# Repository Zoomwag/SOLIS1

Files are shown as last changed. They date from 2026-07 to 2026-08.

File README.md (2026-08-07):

<div align="center">

# Solis 1 CanSat


</div>

---

## About

**Solis 1** is my custom-built CanSat project, designed to fit all the main systems of a small satellite inside a compact cylindrical enclosure.

The CanSat measures approximately:

* **64 mm in diameter**
* **110 mm tall**

The project includes a custom flight computer PCB, a lightweight enclosure, onboard software, a recovery system and a ground station.

The aim of Solis 1 is to create a compact and system that can collect data during a test flight, transmit information back to the ground and safely return for recovery.

---

## Project Goals

The main goals of the project are to:

* Design a fully custom flight computer
* Fit the complete system inside the CanSat enclosure
* Collect and store flight data
* Transmit data to a ground station
* Create a lightweight but strong structure
* Test the CanSat through multiple ground and flight tests
* Learn more about PCB design, electronics, programming and engineering

---

## CanSat Design

The outside structure is designed to protect the electronics while keeping the CanSat lightweight and easy to assemble.

The design includes mounting points for the flight computer, battery and other internal parts. It will also allow the CanSat to be opened for maintenance, testing and repairs.

<!-- Add an image or render of the complete CanSat here -->

---

## Flight Computer PCB

The Solis 1 flight computer is a custom PCB designed specifically for this project.

It will connect the main electronics together and reduce the amount of loose wiring inside the CanSat. The PCB is being designed to be compact, organised and easy to test.

<!-- Add a PCB render or photograph here -->

---

## PCB Schematic

The schematic shows how the components  on the flight computer are connected together



---

## PCB Layout

The board is designed to fit inside the Solis 1 enclosure while leaving enough space for mounting holes, connectors and other internal parts.







I even included some really nice graphics on the back

---

## BOM


Here you can see the bom for Solis 1

---

## Mechanical Design

This includes the outer enclosure, internal mounts, PCB supports and recovery-system parts. The design needs to be compact, lightweight and strong enough to protect the electronics during testing and landing.






---

---

## Future Plans

Once the first version of Solis 1 has been assembled, it will go through several stages of testing.

These will include checking the electronics, testing the software, confirming that the ground station receives data and making sure the enclosure protects the internal components.

The results from each test will be used to improve future versions of the CanSat.

---

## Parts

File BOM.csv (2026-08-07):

Name | Purpose | Qty | Total (USD) | Link | Distributor
PCB | PCB | 5 | $130.00 | JLCPCB | jlcpcb
Adafruit RFM95W LoRa Radio Transceiver Breakout - 868 or 915 MHz (RadioFruit) | LORA | 1 | $27.00 | https://thepihut.com/products/adafruit-rfm95w-lora-radio-transceiver-breakout-868-or-915-mhz | thepihut
Adafruit BME280 I2C or SPI Temperature Humidity Pressure Sensor (STEMMA QT) | environmetnal sensor | 1 | $20.00 | https://thepihut.com/products/adafruit-bme280-i2c-or-spi-temperature-humidity-pressure-sensor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 | thepihut
MicroSD card breakout board+ | SDcard | 1 | $11.00 | https://thepihut.com/products/adafruit-microsd-card-breakout-board?variant=27739995217 | thepihut
Adafruit LSM6DSOX + LIS3MDL - Precision 9 DoF IMU (STEMMA QT / Qwiic | IMU | 5 | $27.00 | https://thepihut.com/products/adafruit-lsm6dsox-lis3mdl-precision-9-dof-imu?variant=31618642182206 | thepihut
2.0mm Pitch 6-pin Cable Matching Pair - JST PH Compatible | wire | 2 | $3.00 | https://thepihut.com/products/2-0mm-pitch-6-pin-cable-matching-pair-jst-ph-compatible?variant=40200490877123 | thepihut
Qwiic/STEMMA QT-Compatible Cable - JST-SH 4-Pin (50mm) | wire | 6 | $10.00 | https://thepihut.com/products/stemma-qt-qwiic-jst-sh-4-pin-cable?variant=31257729073214 | thepihut
Shipping |  |  | $5.50
Total |  |  | $233.50

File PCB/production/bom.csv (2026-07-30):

Designator | Footprint | Quantity | Value | LCSC Part #
C15, C18, C22 | 0805 | 3 | 10uF
C16, C19 | 0805 | 2 | 2.2uF
C17 | 1206 | 1 | 47uF
C20 | 1206 | 1 | 22uF
C21, C24 | 0805 | 2 | 1uF
C23 | 0603 | 1 | 100nF
D1 | 0805 | 1 | LED
D3 | D_SMA | 1 | SS14-E3/5AT
F2 | MFNSMF0758X2 | 1 | MF-NSMF075_8X-2
IC4 | SON40P220X200X80-11N | 1 | BQ25185DLHR
IC5 | ESP32S3WROOM1UN16R8 | 1 | ESP32-S3-WROOM-1U-N16R8
J11, J15, J16, J4, J5 | JST_SH_BM04B-SRSS-TB_1x04-1MP_P1.00mm_Vertical | 5 | Conn_01x04_Socket
J12, J13 | JST_PH_B8B-PH-K_1x08_P2.00mm_Vertical | 2 | Conn_01x08_Socket
J14 | PinHeader_1x09_P2.54mm_Vertical | 1 | Conn_01x09_Socket
J6 | USB_C_Receptacle_GCT_USB4105-xx-A_16P_TopMnt_Horizontal | 1 | USB_C_Receptacle_USB2.0_16P
J7 | PinHeader_1x02_P2.54mm_Vertical | 1 | Battery
L2 | DFE2HCAH1R0MJ0L | 1 | 1uH
R10, R17, R23, R28 | 0603 | 4 | 10K
R11 | 0603 | 1 | 0
R15, R16 | 0603 | 2 | 5.1K
R18 | 0603 | 1 | 18K
R19 | 0603 | 1 | 1K
R20 | 0603 | 1 | 511K
R21 | 0603 | 1 | 91K
R22 | 0603 | 1 | 100K
R24, R25 | 0603 | 2 | 22
R26, R27 | 0603 | 2 | 4.7K
S2 | SSAJ110100_1 | 1 | SSAJ110100
SW5, SW6 | SW_Push_SPST_NO_Alps_SKRK | 2 | SW_Push
U3 | SOTFL50P160X60-8N | 1 | TPS631000DRLR

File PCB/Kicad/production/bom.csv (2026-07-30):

Designator | Footprint | Quantity | Value | LCSC Part #
AC2 | LSM6DS3USTR | 1 | LSM6DSOTR
C1, C15, C18, C22, C5 | 0805 | 5 | 10uF
C16, C19 | 0805 | 2 | 2.2uF
C17, C6 | 1206 | 2 | 47uF
C2, C23, C25, C26, C27, C28, C4, C8 | 0603 | 8 | 100nF
C20 | 1206 | 1 | 22uF
C21, C24, C3 | 0805 | 3 | 1uF
C7 | 1206 | 1 | 470uF
D1, D2 | 0805 | 2 | LED
D3, D4 | D_SMA | 2 | SS14-E3/5AT
F2 | MFNSMF0758X2 | 1 | MF-NSMF075_8X-2
IC1 | SOT65P210X110-6N | 1 | TPS22919DCKT
IC4 | SON40P220X200X80-11N | 1 | BQ25185DLHR
IC5 | ESP32S3WROOM1UN16R8 | 1 | ESP32-S3-WROOM-1U-N16R8
IC6 | BMP390 | 1 | BMP390
J1 | 1040310811 | 1 | Micro_SD_Card_Det1
J10 | PinHeader_2x09_P2.54mm_Vertical | 1 | Camera
J2 | PinHeader_1x09_P2.54mm_Vertical | 1 | LORA MODULE
J3 | PinHeader_1x03_P2.54mm_Vertical | 1 | Conn_01x03_Pin
J6 | USB_C_Receptacle_GCT_USB4105-xx-A_16P_TopMnt_Horizontal | 1 | USB_C_Receptacle_USB2.0_16P
J7 | PinHeader_1x02_P2.54mm_Vertical | 1 | Battery
J9 | PinHeader_1x04_P2.54mm_Vertical | 1 | Conn_01x04_Socket
L2 | DFE2HCAH1R0MJ0L | 1 | 1uH
R1, R24, R25 | 0603 | 3 | 22
R10, R17, R23, R28, R3, R4, R5, R6, R7, R8, R9 | 0603 | 11 | 10K
R11 | 0603 | 1 | 0
R12, R26, R27 | 0603 | 3 | 4.7K
R13, R2, R22 | 0603 | 3 | 100K
R14 | 0603 | 1 | 220
R15, R16 | 0603 | 2 | 5.1K
R18 | 0603 | 1 | 18K
R19 | 0603 | 1 | 1K
R20 | 0603 | 1 | 511K
R21 | 0603 | 1 | 91K
SW5, SW6 | SW_Push_SPST_NO_Alps_SKRK | 2 | SW_Push
TP1 | TestPoint_Pad_1.0x1.0mm | 1 | GND1
TP2 | TestPoint_Pad_1.0x1.0mm | 1 | TestPoint
TP3 | TestPoint_Pad_1.0x1.0mm | 1 | GND2
TP4 | TestPoint_Pad_1.0x1.0mm | 1 | VBAT
TP5 | TestPoint_Pad_1.0x1.0mm | 1 | SYS_SW
TP6 | TestPoint_Pad_1.0x1.0mm | 1 | 3v3
TP8 | TestPoint_Pad_1.0x1.0mm | 1 | SDA
TP9 | TestPoint_Pad_1.0x1.0mm | 1 | SCL
U3 | SOTFL50P160X60-8N | 1 | TPS631000DRLR

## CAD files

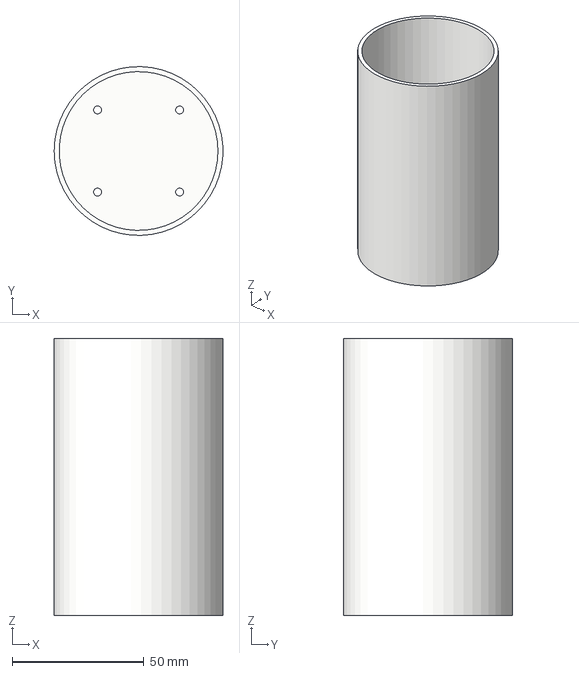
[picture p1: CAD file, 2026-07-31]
SOLIS CAD/3D Print Files/Shell.step
63.9 x 64.0 x 105.0 mm

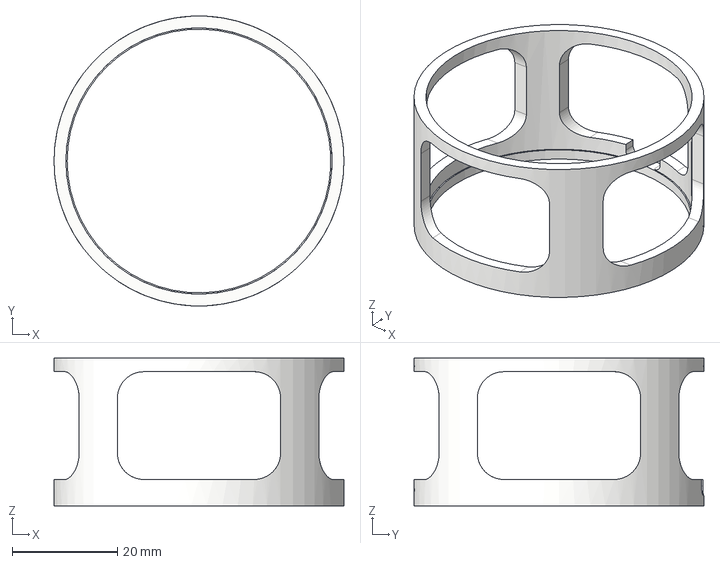
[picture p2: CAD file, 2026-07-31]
SOLIS CAD/3D Print Files/Flight computer mount.step
55.0 x 55.0 x 28.0 mm

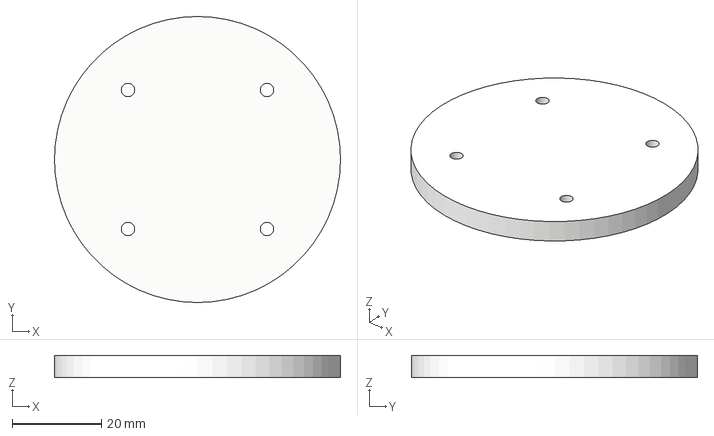
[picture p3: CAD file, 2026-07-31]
SOLIS CAD/3D Print Files/LID.step
64.0 x 64.0 x 5.00 mm

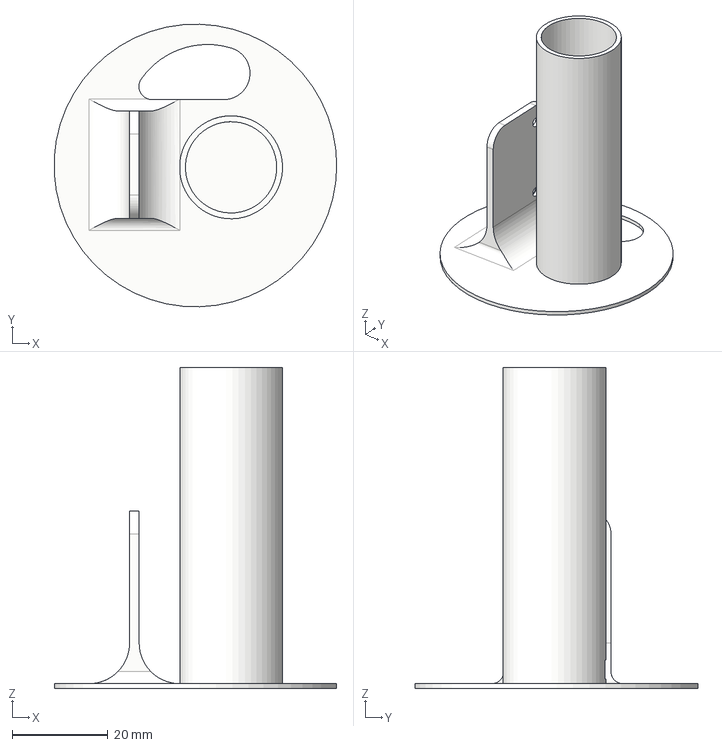
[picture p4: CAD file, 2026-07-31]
SOLIS CAD/3D Print Files/Sensor and battery bay.step
58.9 x 59.0 x 67.0 mm

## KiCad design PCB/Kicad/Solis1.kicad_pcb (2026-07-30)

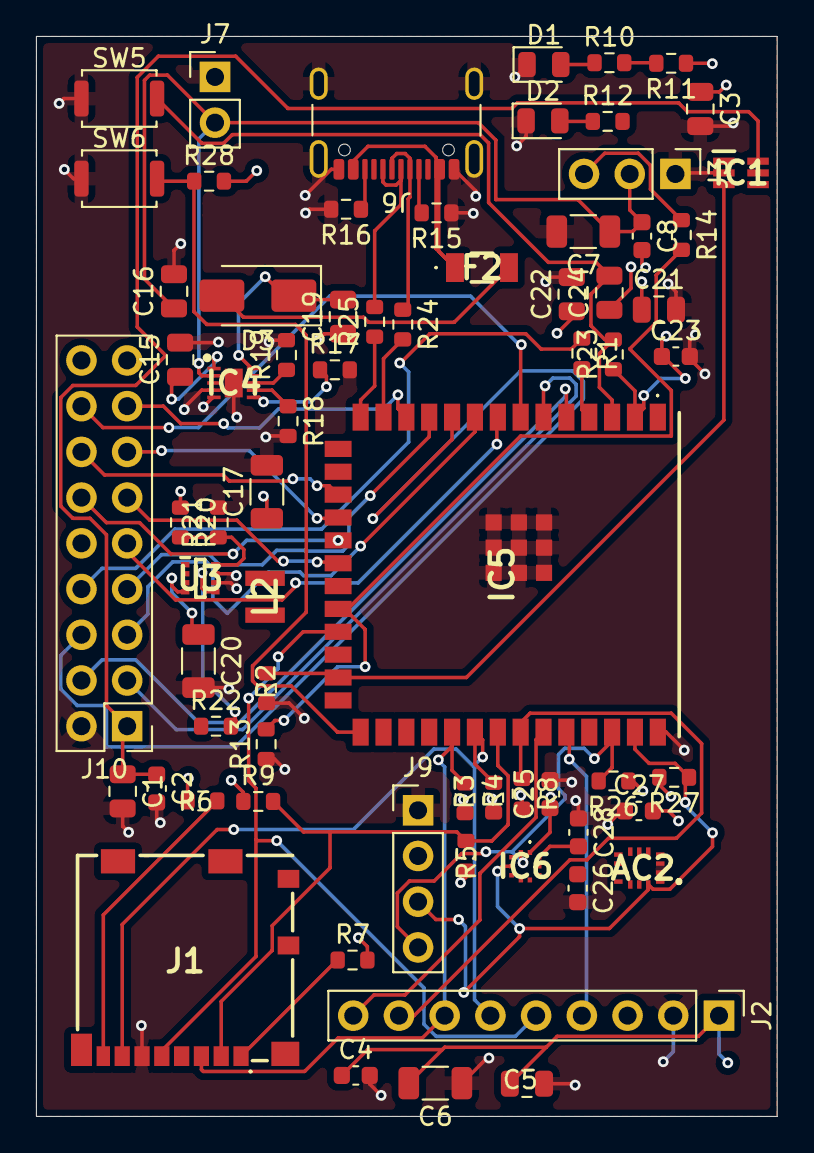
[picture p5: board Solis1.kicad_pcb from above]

Board: 4 copper layers, 41.2 x 60.0 mm, 69 parts (0 on the bottom side), 55 nets.

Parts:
AC2: LSM6DSOTR; LSM6DS3USTR
C1, C5, C15, C22: 10uF; C_0805_2012Metric
C2, C4, C8, C23, C25, C26, C27, C28: 100nF; C_0603_1608Metric
C3, C21, C24: 1uF; C_0805_2012Metric
C6, C17: 47uF; C_1206_3216Metric
C7: 470uF; C_1206_3216Metric
C16, C19: 2.2uF; C_0805_2012Metric
C20: 22uF; C_1206_3216Metric
D1, D2: LED; LED_0805_2012Metric
D3: SS14-E3/5AT; D_SMA
F2: MF-NSMF075_8X-2; MFNSMF0758X2
IC1: TPS22919DCKT; SOT65P210X110-6N
IC4: BQ25185DLHR; SON40P220X200X80-11N
IC5: ESP32-S3-WROOM-1U-N16R8; ESP32S3WROOM1UN16R8
IC6: BMP390
J1: Micro_SD_Card_Det1; 1040310811
J2: LORA MODULE; PinHeader_1x09_P2.54mm_Vertical
J3: Conn_01x03_Pin; PinHeader_1x03_P2.54mm_Vertical
J6: USB_C_Receptacle_USB2.0_16P; USB_C_Receptacle_GCT_USB4105-xx-A_16P_TopMnt_Horizontal
J7: Battery; PinHeader_1x02_P2.54mm_Vertical
J9: Conn_01x04_Socket; PinHeader_1x04_P2.54mm_Vertical
J10: Camera; PinHeader_2x09_P2.54mm_Vertical
L2: 1uH; DFE2HCAH1R0MJ0L
R1, R24, R25: 22; R_0603_1608Metric
R2, R13, R22: 100K; R_0603_1608Metric
R3, R4, R5, R6, R7, R8, R9, R10, R17, R23, R28: 10K; R_0603_1608Metric
R11: 0; R_0603_1608Metric
R12, R26, R27: 4.7K; R_0603_1608Metric
R14: 220; R_0603_1608Metric
R15, R16: 5.1K; R_0603_1608Metric
R18: 18K; R_0603_1608Metric
R19: 1K; R_0603_1608Metric
R20: 511K; R_0603_1608Metric
R21: 91K; R_0603_1608Metric
SW5, SW6: SW_Push; SW_Push_SPST_NO_Alps_SKRK
U3: TPS631000DRLR; SOTFL50P160X60-8N

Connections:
+3V3: AC2.5 (VDDIO), AC2.8 (VDD), AC2.12 (CS), C3.1, C4.1, C5.1, C6.2, C17.1, C21.1, C22.1, C23.1, C25.1, C26.1, C27.2, C28.2, IC1.1 (IN), IC5.2 (3V3), IC6.1 (VDDIO), IC6.6 (CSB), IC6.10 (VDD), J1.4 (VDD), J2.1, J9.2, R3.2, R4.2, R5.1, R6.1, R7.2, R8.2, R9.1, R11.1, R20.1, R23.1, R26.1, R27.2, R28.2, U3.1 (VOUT)
/CAM_3V3: C1.1, C2.1, IC1.5 (QOD), IC1.6 (OUT), J10.1, R12.2
/CAM_PWR: IC1.3 (ON), IC5.25 (IO48), R2.1
/CHARGER_IN: C19.2, D3.1 (K), IC4.10 (IN)
/Camera_D0: IC5.7 (IO7), J10.16
/Camera_D1: IC5.12 (IO8), J10.15
/Camera_D2: IC5.17 (IO9), J10.14
/Camera_D3: IC5.18 (IO10), J10.13
/Camera_D4: IC5.19 (IO11), J10.12
/Camera_D5: IC5.20 (IO12), J10.11
/Camera_D6: IC5.21 (IO13), J10.10
/Camera_D7: IC5.8 (IO15), J10.9
/Camera_HREF: IC5.10 (IO17), J10.6
/Camera_PCLK: IC5.11 (IO18), J10.7
/Camera_SCCB_SCL: IC5.6 (IO6), J10.3
/Camera_SCCB_SDA: IC5.5 (IO5), J10.4
/Camera_VSYNC: IC5.9 (IO16), J10.5
/Camera_XCLK: IC5.4 (IO4), R1.2
/LORA_CS: IC5.34 (IO41), J2.8, R8.1
/LORA_DIO0: IC5.36 (RXD0), J2.4
/LORA_RST: IC5.35 (IO42), J2.9
/SD_CS: IC5.33 (IO40), J1.2 (DAT3/CD), R5.2, R9.2
/SPI_MISO: IC5.32 (IO39), J1.7 (DAT0), J2.6, R4.1
/SPI_MOSI: IC5.31 (IO38), J1.3 (CMD), J2.7, R3.1
/SPI_SCK: IC5.23 (IO21), J1.5 (CLK), J2.5
/SYS_RAW: C15.1, C20.1, IC4.1 (SYS), R22.1, U3.4 (VIN)
/Sensor_I²C_SCL: AC2.13 (SCL), IC5.38 (IO2), IC6.2 (SCK), J9.4, R26.2
/Sensor_I²C_SDA: AC2.14 (SDA), IC5.39 (IO1), IC6.4 (SDI), J9.3, R27.1
/Servo1_PWM: IC5.22 (IO14), R13.2, R14.2
/USB_D+: J6.A6 (D+), J6.B6 (D+), R25.2
/USB_D-: J6.A7 (D-), J6.B7 (D-), R24.1
/USB_FUSED: D3.2 (A), F2.2
/USB_VBUS: F2.1, J6.A4 (VBUS), J6.A9 (VBUS), J6.B4 (VBUS), J6.B9 (VBUS)
/VBAT: C7.1, C8.1, C16.1, IC4.2 (BAT), J3.2, J7.2
GND: AC2.1 (SDO/SA0), AC2.2 (SDX), AC2.3 (SCX), AC2.6 (GND_1), AC2.7 (GND_2), C1.2, C2.2, C3.2, C4.2, C5.2, C6.1, C7.2, C8.2, C15.2, C16.2, C17.2, C19.1, C20.2, C21.2, C22.2, C23.2, C24.1, C25.2, C26.2, C27.1, C28.1, D1.1 (K), D2.1 (K), IC1.2 (GND), IC4.4 (~CE), IC4.5 (GND), IC4.11 (EP), IC5.1 (GND_1), IC5.40 (GND_2), IC5.41 (GND_3), IC5.42 (GND_4), IC5.43 (GND_5), IC5.44 (GND_6), IC5.45 (GND_7), IC5.46 (GND_8), IC5.47 (GND_9), IC5.48 (GND_10), IC5.49 (GND_11), IC6.3 (VSS_1), IC6.5 (SDO), IC6.8 (VSS_2), IC6.9 (VSS_3), J1.6 (VSS), J2.2, J3.1, J6.A1 (GND), J6.A12 (GND), J6.B1 (GND), J6.B12 (GND), J6.SH (SHIELD), J7.1, J9.1, J10.2, R2.2, R13.1, R15.1, R16.2, R17.2, R18.2, R19.2, R21.2, SW5.1, SW6.1, U3.6 (MODE), U3.7 (GND)
unnamed: D1.2 (A), R10.1
unnamed: D2.2 (A), R12.1
unnamed: IC4.7 (ILIM/VSET), R18.1
unnamed: IC4.8 (ISET), R19.1
unnamed: IC4.6 (TS/MR), R17.1
unnamed: C24.2, IC5.3 (EN), R23.2, SW5.2
unnamed: IC5.27 (IO0), R28.1, SW6.2
unnamed: IC5.13 (IO19), R24.2
unnamed: IC5.14 (IO20), R25.1
unnamed: J1.8 (DAT1), R6.2
unnamed: J1.1 (DAT2), R7.1
unnamed: J3.3, R14.1
unnamed: J6.A5 (CC1), R15.2
unnamed: J6.B5 (CC2), R16.1
unnamed: J10.8, R1.1
unnamed: R10.2, R11.2
unnamed: R22.2, U3.5 (EN)
unnamed: R20.2, R21.1, U3.8 (FB)
unnamed: L2.1, U3.3 (LX1)
unnamed: L2.2, U3.2 (LX2)
